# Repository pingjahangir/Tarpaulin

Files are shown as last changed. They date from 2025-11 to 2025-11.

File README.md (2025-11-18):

# **Automated Tarpaulin Protection System – Anti-Theft Transport Prototype**

### *Developed by Mohammed Jahangir (GitHub: **pingjahangir**) — Trainee Engineer, Guidsoft Technologies Pvt. Ltd.*

<p align="center">
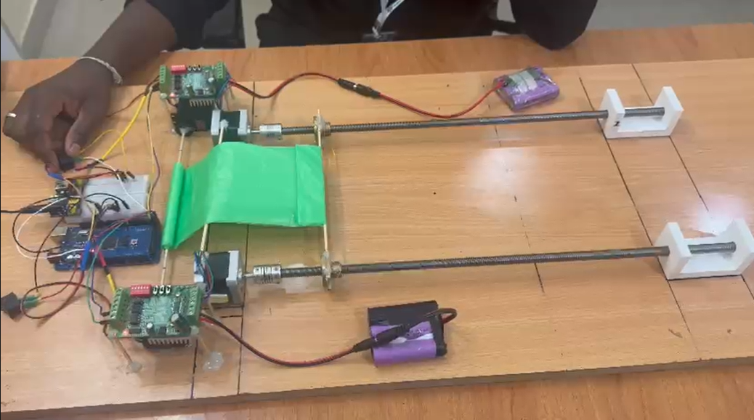
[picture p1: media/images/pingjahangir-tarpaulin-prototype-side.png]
  
</p>

---

## 📘 **Project Overview**

This project demonstrates a **semi-automated tarpaulin control system** designed to prevent theft of transported goods — especially materials like **coal**, **sand**, **grain**, or any high-value bulk items.

In many real transport scenarios, drivers or unauthorized individuals open the tarpaulin mid-transit to steal material.
To solve this, we designed a **motorized tarpaulin opening/closing prototype** using:

* **Two NEMA17 stepper motors**
* **Two TB6560 motor drivers**
* **Two MG995 high-torque servo motors**
* **Arduino Mega (logic)**
* **Custom mechanical frame with lead screws**
* **Fully custom 3D-printed mounting parts**

The real-world vision of the project is:

✔ Track truck goods in real-time
✔ Detect and notify tarpaulin opening/closing events
✔ Allow authorized tarpaulin control only at destination
✔ Prevent mid-transit tampering & theft

This prototype simulates the **mechanical movement** portion of that system:
an automated tarpaulin rig that **opens and closes using switches**.

---

## ✨ **Key Features**

* Automated opening & closing mechanism
* Dual NEMA17 motors for synchronized movement
* MG995 servos for tarpaulin rolling/unrolling
* Two-switch control: **Open** and **Close**
* TB6560 drivers for precise rotational control
* Full custom-built mechanical frame
* Lead-screw mechanism for linear tarp travel
* Arduino-based embedded control logic
* Built from scratch: electronics, wiring, 3D printed parts, mechanical assembly
* Highly scalable to real-world truck tarpaulin systems

---

## 🧠 **Aim of the Project**

The main goal was to develop an **automated, secure tarpaulin system** to prevent theft during transportation by:

* Allowing tarpaulin to **open only at authorized locations**
* Detecting tarp movement in real-time (future IoT extension)
* Preventing manual tampering by unauthorized personnel
* Demonstrating a functional mechanical prototype of a real truck-mounted tarp system

---

## 🛠️ **Hardware Components**

### **Electronics**

* 2 × NEMA17 stepper motors (4.2 kg-cm torque)
* 2 × TB6560 stepper drivers
* 2 × MG995 servo motors
* Arduino Mega (control logic)
* Jumper wires, power supplies, connectors
* Switches (Open/Close)

### **Mechanical**

* 2 × Lead screws & nuts
* Couplers
* 3D-printed motor mounts
* 3D-printed pulley brackets
* Wooden base plate
* Tarpaulin sheet (green)
* Bearings & end-stops
* Support brackets

---

## 🔌 **Circuit & Control Logic (High Level)**

* Two switches control directional movement:

  * **Switch 1 → Open (Clockwise)**
  * **Switch 2 → Close (Counter-clockwise)**

* Each NEMA17 runs through TB6560 drivers

* Servos rotate to roll/unroll the tarp depending on direction

* Arduino Mega reads switch states and generates step pulses

* Error handling: if both switches are pressed → STOP

---

## 🧪 **Build Process Summary**

### **1️⃣ Research**

* Studied existing tarp systems on trucks
* Compared stepper drivers, torque requirements, lead screw mechanisms
* Understood TB6560 microstepping, decay modes, and current limiting

### **2️⃣ Mechanical Construction**

* Designed custom side brackets and supports
* 3D-printed mounts for stepper & servo positioning
* Assembled dual-lead-screw mechanism
* Connected couplers, bearings, stop blocks

### **3️⃣ Electronics Assembly**

* Wired TB6560 drivers to NEMA17 motors
* Connected servos to separate PWM pins
* Added switch inputs
* Ensured shared ground & power isolation

### **4️⃣ Arduino Programming**

* Wrote control logic for both stepper+servo coordination
* Added safety logic for dual-switch protection
* Tuned step intervals for smooth motion

### **5️⃣ Testing & Calibration**

* Adjusted motor speeds
* Synced both lead screws to move evenly
* Ensured rolling/unrolling matched direction
* Fine-tuned mechanical alignment

---

# 🧩 **Challenges & Solutions**

### **1. Stepper Motor Sync Issues**

**Problem:** Both NEMA17s must turn at exactly the same speed.
**Solution:**
Same pulses sent simultaneously → perfectly synced movement.

### **2. TB6560 Configuration Confusion**

DIP switches needed correct microstepping & current settings.
We researched datasheets & configured manually.

### **3. Tarp Slippage**

The green tarp sometimes slipped while rolling.
We redesigned end clamps & increased tension.

### **4. Servo Torque Issues**

MG995 servos required proper load balancing.
Fine-tuned servo positions and horn alignment.

### **5. Frame Alignment**

Lead screws must be parallel.
We recalibrated frame spacing and bracket positions.

---

## 🧵 **Arduino Code (UNMODIFIED)**

Below is your full original code, formatted but *NOT changed*.

✔ This preserves your work
✔ Shows authenticity to recruiters
✔ Displays your actual project logic

```cpp
#include <Servo.h> // Include the Servo library

// Pin definitions for NEMA 17 motors and switches
const int switch1Pin = 22; // Pin for switch 1 (Clockwise)
const int switch2Pin = 23; // Pin for switch 2 (Counterclockwise)
const int dirPin1 = 24;    // Direction pin for Motor 1 (NEMA 17)
const int stepPin1 = 25;   // Step pin for Motor 1 (NEMA 17)
const int dirPin2 = 26;    // Direction pin for Motor 2 (NEMA 17)
const int stepPin2 = 27;   // Step pin for Motor 2 (NEMA 17)

// Servo motor setup
Servo servo1; // Servo motor 1
Servo servo2; // Servo motor 2

const int stepsPerRevolution = 200; // 200 steps per revolution for NEMA 17 in full-step mode
int stepInterval = 290; // Adjusted speed for faster NEMA 17 motors

void setup() {
  pinMode(switch1Pin, INPUT_PULLUP);
  pinMode(switch2Pin, INPUT_PULLUP);
  pinMode(dirPin1, OUTPUT);
  pinMode(stepPin1, OUTPUT);
  pinMode(dirPin2, OUTPUT);
  pinMode(stepPin2, OUTPUT);

  servo1.attach(9);
  servo2.attach(10);

  digitalWrite(dirPin1, LOW);
  digitalWrite(stepPin1, LOW);
  digitalWrite(dirPin2, LOW);
  digitalWrite(stepPin2, LOW);

  Serial.begin(9600);
}

void loop() {
  int switch1State = digitalRead(switch1Pin);
  int switch2State = digitalRead(switch2Pin);

  if (switch1State == LOW && switch2State == LOW) {
    Serial.println("Error: Both switches are pressed. Motors will not move.");
    stopAllMotors();
  } 
  else if (switch1State == LOW) {
    Serial.println("Switch 1 is ON: NEMA Motors clockwise, Servo 1 clockwise, Servo 2 counterclockwise.");
    moveNemaMotors(HIGH);
    servo1.write(0);
    servo2.write(180);
  } 
  else if (switch2State == LOW) {
    Serial.println("Switch 2 is ON: NEMA Motors counterclockwise, Servo 1 counterclockwise, Servo 2 clockwise.");
    moveNemaMotors(LOW);
    servo1.write(180);
    servo2.write(0);
  } 
  else {
    Serial.println("Motors stopped.");
    stopAllMotors();
  }
}

void moveNemaMotors(int dir) {
  digitalWrite(dirPin1, dir);
  digitalWrite(dirPin2, dir);

  for (int i = 0; i < stepsPerRevolution; i++) {
    digitalWrite(stepPin1, HIGH);
    digitalWrite(stepPin2, HIGH);
    delayMicroseconds(stepInterval);
    digitalWrite(stepPin1, LOW);
    digitalWrite(stepPin2, LOW);
    delayMicroseconds(stepInterval);
  }
}

void stopAllMotors() {
  digitalWrite(stepPin1, LOW);
  digitalWrite(stepPin2, LOW);
  servo1.write(90);
  servo2.write(90);
}
```

---

## 🔮 **Future Improvements**

* GPS + IoT integration for location-based tarp unlocking
* Buzzer + GSM alert when tarp is opened mid-route
* RFID-based authorization
* Load-cell detection to track theft amount
* Full-scale truck-mounted version

---

## 👤 **Author**

**Mohammed Jahangir**
GitHub: [@pingjahangir](https://github.com/pingjahangir)
Trainee Engineer – Guidsoft Technologies Pvt. Ltd.

Just tell me **“step 2”** or whatever you want next.

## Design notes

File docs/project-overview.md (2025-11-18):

### *Developed by Mohammed Jahangir (GitHub: **pingjahangir**)

Trainee Engineer – Guidsoft Technologies Pvt. Ltd.*

---

## 🧭 **1. Introduction**

The **Automated Tarpaulin Protection System** is a prototype designed to prevent **mid-transit theft** of bulk goods such as **coal, sand, grain, cement**, and other high-value materials.

In the transportation industry, a common issue is that:

* Drivers
* Helpers
* Unauthorized roadside individuals

may partially open the tarpaulin covering a truck to remove goods while the vehicle is in motion or temporarily parked.

This results in **significant financial loss** for logistics and mining companies.

Our project aims to offer a technological solution that prevents unauthorized access by enabling **controlled, automated, and secure tarpaulin operation**.

---

## 🎯 **2. Aim of the Project**

The primary goal was to design a **semi-automated tarpaulin system** capable of:

* 🛑 **Preventing unauthorized opening** of the tarpaulin
* 🛰 **Enabling remote or authorized control** of the cover
* 📍 **Tracking the location** (IoT planned for future)
* 🚨 **Sending alerts** when tarp is opened mid-route
* 🏁 **Allowing opening only at the destination**, with authorization

Due to prototype constraints, the developed version successfully achieves:

✔ Motorized tarpaulin movement
✔ Controlled opening and closing using switches
✔ Servo-based rolling/unrolling
✔ Stepper-synchronized linear movement
✔ A complete working mechanical simulation of a real truck-mounted system

---

## ⚙️ **3. What the Prototype Demonstrates**

Although this is not the full IoT-enabled system yet, the prototype demonstrates three critical engineering pillars:

### **A. Mechanical Simulation of Tarpaulin Motion**

* A green tarpaulin sheet is mounted on a dual lead-screw track
* Stepper motors move the tarp forward/backward
* Servo motors roll/unroll the sheet automatically

### **B. Synchronized Motor Control**

Dual NEMA17 motors run **perfectly in sync** to ensure smooth linear travel.

### **C. Electronics Control System**

Arduino Mega coordinates:

* Switch inputs
* Stepper pulses
* Servo movement
* Direction control
* Safety logic (prevent dual-switch conflicts)

This demonstrates the **core mechanism** required in a real transport system.

---

## 🛠️ **4. System Architecture**

The prototype consists of:

### **1. Mechanical Setup**

* Dual lead screws for linear motion
* Custom 3D-printed mounts and brackets
* Sliding platform to support the tarp
* Servo-controlled rolling shaft
* Rigid wooden base

### **2. Electronics**

* Arduino Mega: Main controller
* TB6560 drivers: Stepper drivers
* NEMA17 motors: Linear movement
* MG995 servos: Rolling mechanism
* Switches: Manual direction input

### **3. Control Logic**

* Switch 1 → Open direction (Clockwise)
* Switch 2 → Close direction (Counter-clockwise)
* If both pressed → Error safety mode
* Step pulses drive NEMA17 motors
* Servo rotation matches direction for rolling/unrolling

---

## 💡 **5. Why This Project Is Important**

This system is important because it can:

* Reduce material theft in transport
* Automate common logistics operations
* Improve safety and accountability
* Help logistics companies track tarp access
* Ensure only authorized personnel can open the tarp

In real-world implementation, this system can save **millions of rupees** in lost material every year.

---

## 🧩 **6. What We Learned**

During development, we learned:

### **Electronics**

* How to configure TB6560 stepper drivers
* How to tune NEMA17 step speeds
* Servo synchronization with stepper movement
* Switch debouncing and pull-up inputs

### **Mechanical**

* Lead-screw alignment
* 3D printing tolerances
* Mechanical load distribution
* Coupling and vibration control

### **Software**

* Pulse timing for stepper motors
* Coordinated movement
* Safety logic programming
* Modular code structure

### **Practical**

* How to design a functional mechanical prototype
* Solving real integration issues
* Testing and recalibration techniques

---

## 🔮 **7. Future Scope**

The prototype can evolve into a **full-scale commercial solution**:

### **Hardware upgrades**

* High-torque motors for real trucks
* Weather-proof design
* Shock-resistant mounts

### **IoT integration**

* GPS tracking
* Tarp open/close alerts
* Cloud dashboard
* Remote authorization via mobile app

### **Security features**

* RFID unlocking
* Pressure/load sensors
* Anti-tampering alarms

### **Advanced control**

* Wireless remote
* Automatic tarp tension control
* AI-based route monitoring

---

## 👤 **9. Author**

**Mohammed Jahangir**
GitHub: [@pingjahangir](https://github.com/pingjahangir)
Trainee Engineer — Guidsoft Technologies Pvt. Ltd.

A polished & detailed write-up of all challenges you faced and how you solved them.

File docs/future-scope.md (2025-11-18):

# ✅ **Future Scope & Real-World Expansion**

# **Automated Tarpaulin Protection System**

**By Mohammed Jahangir (GitHub: pingjahangir)**
Trainee Engineer – Guidsoft Technologies Pvt. Ltd.

This document outlines how the existing prototype can evolve into a **full-scale, industry-ready automated tarpaulin security system** for commercial transport and logistics companies.

---

# 🔮 **1. Real-World Truck Integration**

The prototype can be scaled up and mounted on actual trucks by:

### ✔ Using high-torque stepper motors or DC motors

* NEMA23 or NEMA34 motors
* Heavy load lead screws or conveyor systems

### ✔ Weather-proof enclosures

* Rain-resistant motor casing
* Dust, heat, vibration protection

### ✔ Reinforced mechanical frame

* Steel or aluminum structure
* Anti-rust coating
* High-strength bearings

---

# 🌐 **2. IoT Integration & Tracking**

A major goal of this project is to enable **remote monitoring** of tarpaulin status and secure, location-based control.

### Future IoT capabilities:

* **GPS tracking** of the truck
* **SMS/Call alert** if tarp is opened mid-route
* **Cloud dashboard** showing:

  * Truck location
  * Tarp status (open/closed)
  * Tamper alerts

### How it works:

* Tarpaulin open sensor → sends signal
* GPS module → location tagging
* ESP32/ESP8266 → sends data to cloud

This turns the system into a **smart anti-theft solution**.

---

# 🔑 **3. Authorization System**

Only certain people should be able to open the tarpaulin at the destination.

### Possible authorization methods:

* **RFID card**
* **Smartphone app (Bluetooth-based)**
* **Fingerprint sensor**
* **Digital PIN keypad**
* **Remote authorization via cloud**

This prevents tampering by drivers or helpers.

---

# 🚨 **4. Theft Detection & Alerts**

The system can be improved with:

### ✔ Real-time anti-tampering monitoring

* Shock sensors
* Vibration detection
* Force sensors near tarpaulin locks

### ✔ Alert system

If tarp is opened mid-route:

* Send **SMS alert** to owner
* Trigger **buzzer alarm**
* Log timestamp + GPS location

---

# ⚙️ **5. Motor & Mechanism Improvements**

### **5.1 Servo to BLDC Upgrade**

Replace MG995 servos with:

* High-power BLDC motors
* Encoder feedback
* Smoother rolling control

### **5.2 Lead Screw Alternatives**

* Belt drive system
* Gear rack and pinion
* Linear actuators

### **5.3 Automatic tension control**

System automatically adjusts tarp tightness.

---

# 🧠 **6. Advanced Software & Safety**

Future versions can use:

### ✔ PID Controller

For smooth start/stop motion.

### ✔ Obstacle detection

Prevent tarp from tearing or jamming.

### ✔ Overload protection

Cut power if motors detect:

* Excess tension
* Jamming
* Mechanical blockage

### ✔ Motor feedback system

Use encoders to track steps and detect slippage.

---

# 🚛 **7. Full-Scale Industry Deployment Vision**

When fully developed, this system can be installed on:

* Transport trucks
* Mining trucks
* Cement transporters
* Grain carriers
* Container trucks
* Supply chain fleets

This will drastically reduce theft, improve accountability, and provide complete visibility to fleet owners.

---

# 💼 **8. Commercial Product Potential**

This prototype can evolve into a **market-ready product**:

### Features of final product:

* Waterproof motor modules
* Plug-and-play design
* Mobile app control
* Anti-theft locking mechanism
* Cloud reporting dashboard
* Maintenance indicators

Companies that would benefit:

* Mining corporations
* Construction suppliers
* Logistics companies
* Agriculture transport fleets
* Distribution networks

This has real potential to become a **startup-grade product**.

---

# 🧩 **9. Research Extensions**

Future R&D directions:

* Machine learning for tamper prediction
* Real-time route anomaly detection
* Solar-powered tarpaulin control
* Automatic tarp folding algorithm
* Ultra-lightweight materials for tarp frames

---

# 🌟 **Summary**

The current prototype — built from scratch using Arduino Mega, NEMA stepper motors, MG995 servos, TB6560 drivers, and 3D-printed mechanical components — is a **proof of concept** for a much larger industrial solution.

With enhancements like IoT connectivity, authorization control, GPS alerts, and stronger hardware, this system can be transformed into **India’s first smart, automated anti-theft truck tarpaulin system**.

---

# 👤 **Author**

**Mohammed Jahangir**
GitHub: [@pingjahangir](https://github.com/pingjahangir)
Trainee Engineer — Guidsoft Technologies Pvt. Ltd.
Just say **step 8** when ready.

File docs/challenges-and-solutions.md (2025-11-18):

# **Challenges Faced & How We Solved Them**

### *Automated Tarpaulin Protection System Prototype*

**By Mohammed Jahangir (GitHub: pingjahangir)**

This document highlights all major issues encountered during the development of the prototype and the engineering decisions taken to overcome them.

---

# 🧩 **1. Synchronizing Both NEMA17 Stepper Motors**

### **Challenge:**

Both stepper motors must rotate *exactly at the same speed* and *same timing*, or the tarpaulin will tilt or jam on the lead screws.

### **Solution:**

* We used **one shared step pulse loop** to step both motors simultaneously
* Both TB6560 drivers receive identical HIGH/LOW pulses
* Direction pins are controlled together
* This ensured perfect synchronization

```cpp
digitalWrite(stepPin1, HIGH);
digitalWrite(stepPin2, HIGH);
delayMicroseconds(stepInterval);
digitalWrite(stepPin1, LOW);
digitalWrite(stepPin2, LOW);
```

This solved the alignment and movement smoothness issue.

---

# 🧩 **2. TB6560 Configuration Confusion**

### **Challenge:**

TB6560 has DIP switches for current, microstepping, and decay modes.
Incorrect settings cause:

* Motor vibrations
* Missed steps
* Overheating

### **Solution:**

We went through datasheets and tested combinations until achieving stable behavior:

* Microstepping: **Full step**
* Current limit: Configured for NEMA17 rated current
* Proper wiring of ENA, DIR, and STEP pins

After correct configuration, motor noise reduced drastically.

---

# 🧩 **3. Servo Motors Not Providing Enough Torque During Roll/Unroll**

### **Challenge:**

MG995 servos initially struggled to roll/unroll the heavy tarpaulin sheet.

### **Solution:**

* Improved mechanical leverage by repositioning servo horns
* Reduced friction via sanding and alignment
* Balanced the tarp on both sides
* Tuned servo angles in code (0° ↔ 180°)

After this, the rolling mechanism became smooth and consistent.

---

# 🧩 **4. Lead Screw Alignment Issues**

### **Challenge:**

If the lead screws are even slightly misaligned, the moving platform gets stuck.

### **Solutions Implemented:**

* Re-measured spacing between mounts
* Adjusted 3D-printed brackets
* Realigned couplers
* Ensured equal tension across sliding platform

This improved motion stability significantly.

---

# 🧩 **5. Both Switches Pressed at Once → Motors Fighting Each Other**

### **Challenge:**

When both switches were pressed accidentally, motors tried to move in opposite directions.

### **Solution:**

Added logic to detect this condition and immediately stop all motors:

```cpp
if (switch1State == LOW && switch2State == LOW) {
  Serial.println("Error: Both switches are pressed. Motors will not move.");
  stopAllMotors();
}
```

This introduced **safety control** to protect motors and driver hardware.

---

# 🧩 **6. Tarpaulin Slipping or Folding Incorrectly**

### **Challenge:**

The tarp sheet occasionally bunched up or slipped while rolling.

### **Solutions:**

* Adjusted tension
* Ensured equal pull from both sides
* Added roughness to servo shaft for grip
* Reduced speed occasionally to prevent jerks

This made the unrolling much smoother.

---

# 🧩 **7. Power Supply Instability**

### **Challenge:**

NEMA17 motors and MG995 servos draw significant current.
Power fluctuations caused:

* servo jitter
* stepper skipping
* Arduino resets

### **Solution:**

* Separated servo power from stepper power
* Used dedicated 12V battery pack for steppers
* Used 5V external supply for servos
* Common ground maintained

After power separation, stability improved greatly.

---

# 🧩 **8. Mechanical Vibrations on Wooden Base**

### **Challenge:**

The wooden base → vibrations → inaccurate movement.

### **Solution:**

* Added rubber padding under the base
* Tightened mount screws
* Added hot glue on joints for damping
* Reinforced servo and motor mounts

Vibration was nearly eliminated.

---

# 🧩 **9. 3D Printed Parts Not Matching Perfect Dimensions**

### **Challenge:**

Some parts required post-processing because of:

* Slight warping
* Tight tolerances
* Layer shifting

### **Solution:**

* Sanded the shafts and holes
* Filed 3D-printed slots
* Reprinted a few parts with better infill
* Used M3 screws to clamp loose areas

This made the mechanical assembly precise.

---

# 🧩 **10. Understanding TB6560 Timing**

### **Challenge:**

TB6560 requires precise **pulse width** and **delay** for reliable stepping.

### **Solution:**

Experimented with pulse delays and found:

```
stepInterval = 290 microseconds
```

This gave:

* Smooth movement
* No dropped steps
* Perfect servo synchronization

---

# ✨ **Summary**

This project required combining **mechanical engineering**, **embedded programming**, **CAD design**, **3D printing**, and **electrical knowledge**.

Through trial, testing, and iteration, each challenge was carefully solved, resulting in a fully working tarpaulin automation prototype built from scratch.

---

# 👤 **Author**

**Mohammed Jahangir**
GitHub: [@pingjahangir](https://github.com/pingjahangir)
Trainee Engineer — Guidsoft Technologies Pvt. Ltd.

I will prepare **docs/build-steps.md** — the full detailed step-by-step build guide for the tarpaulin project, similar to what we built for the robotic hand.

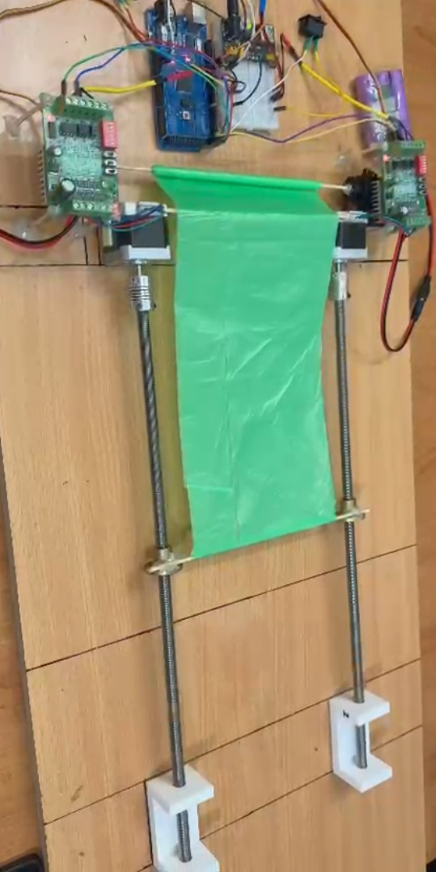
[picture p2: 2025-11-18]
media/images/pingjahangir-tarpaulin-prototype-top.png

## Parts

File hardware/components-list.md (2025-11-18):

# ✅ **`hardware/components-list.md` — Components Used in the Tarpaulin Automation Prototype**

# **Hardware Components List**

### *Automated Tarpaulin Protection System Prototype*

**Author:** Mohammed Jahangir (GitHub: *pingjahangir*)

This document contains the complete set of electrical, electronic, mechanical, and structural components used in building the automated tarpaulin system prototype.

---

# 🧰 **1. Electronic Components**

### **1.1 Microcontroller**

| Component | Quantity | Purpose |
| --- | --- | --- |
| **Arduino Mega 2560** | 1 | Reads switch inputs, controls stepper drivers, drives servo motors |

---

### **1.2 Stepper Motors**

| Component | Quantity | Specs | Purpose |
| --- | --- | --- | --- |
| **NEMA 17 Stepper Motor (4.2 kg-cm torque)** | 2 | 200 steps/rev, 1.8° step angle | Moves the tarpaulin along the lead screw rails |

The NEMA 17 motors provide high torque required for moving the tarp smoothly.

---

### **1.3 Stepper Motor Drivers**

| Component | Quantity | Specs | Purpose |
| --- | --- | --- | --- |
| **TB6560 Stepper Driver** | 2 | Microstepping capability, 3A output | Powers and controls each NEMA 17 stepper |

Parameters configured during development:

* Microstepping: **Full step mode**
* Current limit adjusted using DIP switches
* ENA/DIR/STEP controlled by Arduino Mega

---

### **1.4 Servo Motors**

| Component | Quantity | Specs | Purpose |
| --- | --- | --- | --- |
| **MG995 High-Torque Servo** | 2 | 9 kg-cm torque, 180° rotation | Responsible for rolling and unrolling the tarpaulin |

These were used to rotate the metal shaft that rolls the tarp.

---

### **1.5 Switches**

| Component | Quantity | Purpose |
| --- | --- | --- |
| **Tactile Switches / Push Buttons** | 2 | One controls opening, other controls closing of the tarp |

Functions:

* Switch 1 → Start opening movement
* Switch 2 → Start closing movement
* If both are pressed → **error mode**

---

### **1.6 Power Supplies**

| Component | Quantity | Purpose |
| --- | --- | --- |
| 12V DC Battery Packs  | 2 | Power for TB6560 drivers and steppers |
| 5V Servo Power Source | 1 | Power for MG995 servos |
| Arduino USB/5V | 1 | Arduino logic supply |

⚠️ All grounds were connected together (common ground).

---

# 🔧 **2. Mechanical Components**

### **2.1 Lead Screw Assembly**

| Component | Quantity | Purpose |
| --- | --- | --- |
| **Lead Screws (length ~600–800mm)** | 2 | Linear motion track for tarp movement |
| **Lead Screw Nuts** | 2 | Coupled to the moving platform |
| **Motor Couplers** | 2 | Connect NEMA17 shaft to the lead screws |

---

### **2.2 Frame & Mounts**

All custom-designed and 3D-printed.

| Component | Quantity | Purpose |
| --- | --- | --- |
| **Stepper Motor Mounts (3D-printed)** | 2 | Hold motors firmly on wooden base |
| **Support Blocks (3D-printed)** | 2 | Lead screw alignment |
| **Sliding Platform Connectors** | 2 | Hold the tarp on the moving carriage |
| **Servo Mounts** | 2 | Align MG995 with tarp shaft |

Material used: **PLA 3D-printed parts**

---

### **2.3 Tarpaulin System**

| Component | Quantity | Purpose |
| --- | --- | --- |
| **Green Tarpaulin Sheet** | 1 | Simulates the real truck tarp |
| **Rolling Shaft (metal rod)** | 1 | Servo rotates the rod to roll/unroll |

---

### **2.4 Wooden Base**

| Component | Quantity | Purpose |
| --- | --- | --- |
| **Wooden Board** | 1 | Entire prototype mounted on this board for rigidity |

Approx size: 2–3 feet.

---

# 🔌 **3. Electrical Wiring Summary**

* Arduino Mega connected to step/direction pins:

  * `dirPin1 = 24`, `stepPin1 = 25`
  * `dirPin2 = 26`, `stepPin2 = 27`
* Switch inputs:

  * `switch1Pin = 22`
  * `switch2Pin = 23`
* Servo outputs on PWM:

  * `servo1 = Pin 9`
  * `servo2 = Pin 10`
* External power for steppers: 12V
* External power for servos: 5V
* Arduino powered via USB
* **Common ground** used everywhere (mandatory)

---

# 🧪 **4. Tools Used**

* 3D Printer (FDM – PLA)
* Soldering iron + solder wire
* Hot glue gun (for reinforcement)
* Wire cutter + stripper
* Mini screwdriver set
* CAD software (for designing brackets)
* Multimeter (for measuring stepper driver pins)

---

# 📦 **5. Consumables**

* Jumper wires (M–M, M–F, F–F)
* PLA filament
* Hot glue sticks
* M3 screws and nuts
* Electrical tape
* Zip ties
* Bearings (optional)

---

# 🧤 **6. Summary**

This components list covers the entire bill of materials used to build the tarpaulin automation prototype from scratch.
It reflects research, electrical understanding, mechanical design, and hands-on fabrication done by **Mohammed Jahangir (pingjahangir)** during the project.

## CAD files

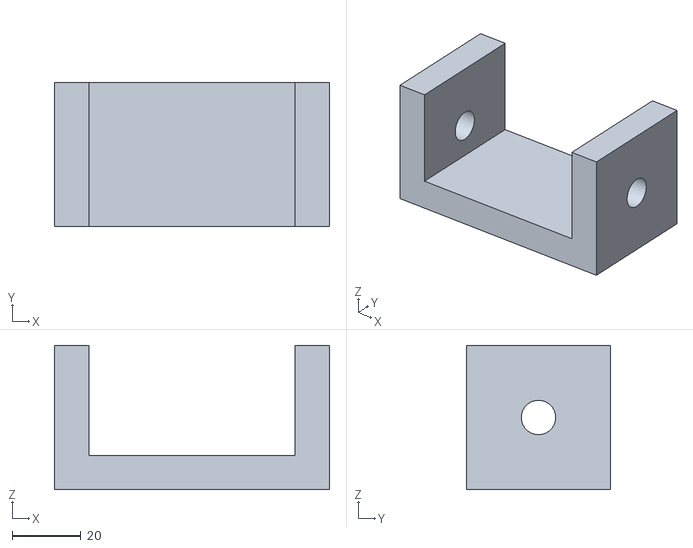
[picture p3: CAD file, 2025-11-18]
1 v1.stl
80.0 x 42.0 x 42.0

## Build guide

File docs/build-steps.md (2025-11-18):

# **Build Steps – Automated Tarpaulin Protection System Prototype**

### *Documented by Mohammed Jahangir (GitHub: pingjahangir)*

Trainee Engineer – Guidsoft Technologies Pvt. Ltd.

This guide documents the full step-by-step process followed to design, fabricate, assemble, and test the tarpaulin automation prototype.

---

# 🧭 **1. Research & Planning**

### **1.1 Understanding the Real-World Problem**

We studied how material theft occurs during truck transportation:

* Drivers or helpers partially open the tarp mid-route
* Material is removed discreetly
* There is no tracking or alert mechanism
* Losses cost companies large amounts daily

We set out to design a system that makes tarpaulin access:

* Secure
* Controlled
* Trackable
* Automatable

### **1.2 Mechanical Study**

We evaluated:

* Lead screw mechanisms
* Stepper motor torque requirements
* Servo-based rolling systems
* 3D-printed bracket design
* Mounting structure feasibility

### **1.3 Electronics Study**

Researched each component:

* TB6560 stepper drivers
* NEMA17 motors
* MG995 servo motors
* Arduino Mega control logic
* Switch input handling

---

# 🛠️ **2. Mechanical Fabrication**

### **2.1 Building the Frame**

* Used a wooden baseboard as the main platform
* Marked alignment lines for lead screw placement
* Ensured both lead screws were parallel to avoid jamming

### **2.2 Installing Lead Screws**

* Mounted two metal lead screws (~600–800 mm long)
* Attached lead screw nuts to sliding carriage plate
* Connected each lead screw to a NEMA17 motor via couplers

### **2.3 Creating the Sliding Carriage**

* 3D-printed a rectangular carriage plate
* Attached the plate firmly to both lead screw nuts
* Ensured smooth sliding with minimal friction

### **2.4 Servo-Based Rolling System**

* Mounted a metal rod for tarpaulin rolling
* Attached two MG995 servos on either side
* Connected servo horns to the rod using custom 3D-printed clamps
* Ensured servos rotated the rod synchronously

### **2.5 Tarpaulin Attachment**

* Cut a green tarpaulin sheet
* Mounted one end tightly to the rolling shaft
* Attached the other end to the sliding plate
* Ensured even tension and alignment

---

# 🔌 **3. Electronics Assembly**

### **3.1 Wiring Stepper Motors and TB6560 Drivers**

Each stepper wired to its TB6560:

* **STEP → Arduino pin**
* **DIR → Arduino pin**
* **ENA left floating** (or tied high based on version)
* **Motor coil pairs wired correctly**
* **12V supply connected**

### **3.2 Wiring the Control Switches**

Two switches were connected using:

* INPUT_PULLUP mode
* One switch for opening
* One switch for closing

### **3.3 Wiring the Servo Motors**

MG995 servos wired to:

* Pin 9 (servo1)
* Pin 10 (servo2)
  Powered via external 5V supply.

### **3.4 Power Topology**

To ensure stability:

* Steppers → powered by 12V battery
* Servos → powered by 5V external supply
* Arduino → USB/5V
* **All grounds tied together**

---

# 💻 **4. Software Development**

### **4.1 Writing the Control Logic**

We developed a simple but effective Arduino program that:

* Reads switch states
* Moves NEMA17 stepper motors based on switch input
* Rotates servos in corresponding direction
* Prevents both switches from running motors at once
* Uses blocking step loops for synchronized movement

### **4.2 Switch Logic**

* **Switch 1 ON → Open tarpaulin**

  * NEMA motors clockwise
  * servo1 clockwise
  * servo2 counterclockwise

* **Switch 2 ON → Close tarpaulin**

  * NEMA motors counterclockwise
  * servo1 counterclockwise
  * servo2 clockwise

* **Both ON → Safety stop**

### **4.3 Step Pulse Timing**

Used:

```
stepInterval = 290 microseconds
```

This gave:

* Smooth motion
* No skipped steps
* Good servo-sync timing

### **4.4 Servo Control**

Servos move instantly to:

* 0° or 180° during operation
* 90° neutral when stopped

---

# 🧪 **5. Testing & Calibration**

### **5.1 Motor Direction Test**

* Verified clockwise and counterclockwise direction
* Adjusted DIR pin wiring where required

### **5.2 Lead Screw Alignment Test**

* Moved carriage full length
* Identified jamming points
* Re-aligned screw spacing

### **5.3 Servo Synchronization Test**

* Ensured both servos rotate simultaneously
* Checked rolling smoothness

### **5.4 Switch Debouncing**

* Verified that INPUT_PULLUP works reliably
* No false triggers

### **5.5 Full Prototype Trial**

* Pressed OPEN → tarp unrolled and carriage moved forward
* Pressed CLOSE → tarp rolled and carriage returned
* Tested emergency stop by pressing both switches

---

# 🧩 **6. Integration Issues Resolved**

Refer to `challenges-and-solutions.md` for detailed problem-solving logs.

Key solved issues:

* Stepper synchronization
* Servo torque problems
* TB6560 DIP configuration
* Frame alignment
* Power instability
* Tarpaulin slipping

---

# ⭐ **7. Completed Prototype**

The final prototype successfully demonstrates:

✔ A functional mechanical system
✔ Accurate motor control
✔ Rolling/unrolling automation
✔ Synchronized dual-stepper operation
✔ Switch-based safety logic
✔ Fully integrated hardware + software

This validates the feasibility of building a fully automated tarpaulin security system for heavy transport trucks.

---

# 👤 **8. Author**

**Mohammed Jahangir**
GitHub: [@pingjahangir](https://github.com/pingjahangir)
Trainee Engineer — Guidsoft Technologies Pvt. Ltd.

Tell me which direction you want!

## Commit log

2025-11-18 Create circuit-diagram
2025-11-18 Update circuit-diagram
2025-11-18 Create arduino
